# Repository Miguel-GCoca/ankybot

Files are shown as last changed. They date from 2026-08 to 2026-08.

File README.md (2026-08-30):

# Ankybot

A custom 12-DOF quadruped robot, trained in NVIDIA Isaac Lab (PPO) and deployed via ROS 2 to a Raspberry Pi 5 + Arduino Uno R3 servo system.

Training montage and demo clips are in [`media/`](media/) — see
`media/training_montage/ankybot_v2_training_montage/rl-video-step-6000.mp4` for
the latest checkpoint's gait, or `media/ankybot_v1.mp4` for a hardware demo.

See [`ENGINEERING.md`](ENGINEERING.md) for a write-up of the harder problems
that came up along the way — a reward-gaming exploit found via playback, a
sim-to-real actuator recalibration, and an ablation study that root-caused a
standing-instability bug to noisy real joint-velocity feedback.

See [`RESTORE.md`](RESTORE.md) for the exact Isaac Sim/Isaac Lab versions this
was built against and how to stand the environment back up from scratch.

## Repo layout

```
training/
  ankybot_v2/     Isaac Lab RL training project — 12-DOF locomotion policy (PPO, rsl_rl)
  ankybot_v3/     Next-generation training project — expanded gait/behavior experiments
                  (standing, walking, multiple gait variants); raw per-iteration
                  checkpoints and TensorBoard logs are gitignored, only final
                  exported policies + run metadata are kept
  custom_assets/  Robot USD descriptions (v1/v2/v3) referenced by the training
                  configs via hard-coded path — see note below

deployment/
  catbot_ws/      ROS 2 workspace: IMU driver, I2C servo bridge, and policy runner
                  nodes that run onboard the Raspberry Pi 5
  hardware/       Robot description (URDF/USD, SolidWorks exports), servo
                  characterization data, and standalone policy deployment scripts

media/            Training montage videos and hardware demo clips
```

## Pipeline

1. **Train** a locomotion policy in Isaac Lab (`training/`), using a 48-observation
   layout (IMU angular velocity, projected gravity, IMU linear acceleration,
   velocity command, joint positions/velocities, previous action) and 12
   joint-position actions.
2. **Validate** the exported policy (`exported/policy.pt` / `policy.onnx`) in sim
   across forward, lateral, and yaw motions.
3. **Deploy** onboard via the ROS 2 `ankybot_policy_runner` node
   (`deployment/catbot_ws/src/ankybot_policy_runner`), which loads the ONNX
   policy and drives the physical servos through the I2C bridge.

## Note on running the training projects

`ankybot_v2.py` and `ankybot_v3.py` hard-code an absolute path to their USD
asset (`/workspace/custom_assets/...`), matching the layout inside the
original `isaac-lab-base` Docker container. To run either project outside
that container, either recreate the same absolute path or update the path in
the task config to point at this repo's `training/custom_assets/`.

## Status

Complete! Awarded "Faculty's Choice" at University of Central Florida Summer '26 senior design showcase.

## License

MIT — see [`LICENSE`](LICENSE).

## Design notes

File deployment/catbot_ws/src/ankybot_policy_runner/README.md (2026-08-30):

# ankybot_policy_runner — fixing "too fast / steps too small"

Observed on hardware with `low_gait_v1_rec1`: gait cadence looks too fast and
individual steps are too short compared to what the sim trained. Root cause
diagnosed 2026-07-19: `action_filter_alpha` in `config/ankybot_policy.yaml`
heavily low-pass-filters the policy's raw output before it's scaled into a
joint target, and this filter has **no counterpart in the sim the policy was
trained in** — sim applies the raw scaled action directly, every step, with
no smoothing. See MANUAL.txt for how the filter math works.

Changes below, roughly ordered by how directly they target the diagnosed
cause. None of these have been tried on hardware yet — test one at a time so
you can tell what actually moved the needle.

## 1. Lower `action_filter_alpha` (most direct fix)

`config/ankybot_policy.yaml`, `action_filter_alpha: 0.8` -> try something
lower. At `alpha=0.8` the filtered action only moves 20% of the way to the
new raw output per 20ms tick (effective lag ~100ms, about 5 control periods)
- more than enough to clip the peak amplitude off a fast leg swing before it
completes. Suggested path: step it down incrementally (e.g. 0.8 -> 0.5 ->
0.3 -> 0.0) rather than jumping straight to 0, since there may be an
undocumented reason it was set this high (taming real servo/feedback jitter,
protecting mechanics from abrupt commands) that a sudden drop to 0 could
re-expose. Watch for: stride length recovering (good), buzzing/oscillating
joints or servo chatter appearing (bad, back off).

This is a runtime YAML value — no rebuild needed, just edit and relaunch.

## 2. Train the filter into the policy instead of removing it

If dropping `action_filter_alpha` reintroduces jitter/instability that it
was actually needed for, the better long-term fix is to add an equivalent
smoothing step inside the sim actuator/action pipeline during training, so
the policy learns a gait that already accounts for filtered output, instead
of learning an unfiltered gait and then filtering it after the fact at
deploy time. This is a training-side change (not in this package) — flag it
back to the Isaac Lab side if option 1 alone doesn't resolve it.

## 3. Re-check `action_scale` / `action_clip` after any retrain

Currently `action_scale: 0.4` and `action_clip: 1.4923` match
`ActionsCfg.joint_position` in `ankybot_v3.py` exactly, so they are not the
cause of the current symptom. But these are two independent files that have
to be kept in sync by hand — if `ankybot_v3.py`'s `scale`/`clip` ever change
in a future retrain, this yaml needs the same update or you get exactly this
class of bug again (silent amplitude mismatch, no error, no crash).

## 4. Verify real control-loop timing matches `control_dt`

`control_dt: 0.02` (50Hz) must match what the policy was actually trained
at (`decimation(10) * sim.dt(0.002)`). The joint-feedback path has
documented jitter (~2-36ms spread depending on sensor, see the main
project CLAUDE.md's "Hardware Feedback Layer"/IMU sections) — if the real
achieved loop rate drifts meaningfully from 50Hz, that's a second source of
timing mismatch between what the policy expects and what it gets, on top of
the filter. Not the primary suspect here, but worth ruling out if lowering
`action_filter_alpha` alone doesn't fully fix stride length.

## 5. Consider deploying a newer checkpoint

`low_gait_v1_rec1` was trained under the original provisional PD gains
(stiffness 20/20/18, damping 0.8), before the datasheet-derived stiffness/
damping and the measured command-delay actuator (`DelayedPDActuatorCfg`,
0-30ms) were added. The current best checkpoint in the same resume-chain
lineage is `low_gait/v2_recovery2_rand` (already exported to
`catbot_ws/policies/v2_recovery2_rand_2997/`). Because that policy was
trained with a modeled command delay already baked in, it may need *less*
deploy-side smoothing to behave well than `v1_rec1` did — worth testing
after trying option 1, not instead of it, since it's a different variable.

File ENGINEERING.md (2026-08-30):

# Engineering Notes

This project kept a very detailed internal dev log throughout — day-by-day
training runs, root-cause diagnoses, every fix and why it was made. This file
is a curated, human-readable summary of the parts of that log worth reading:
the real engineering problems that came up training and deploying a from-scratch
quadruped, and how they were tracked down.

## Training a policy that doesn't cheat

The reward function for this robot combines velocity tracking, a three-leg
gait-stance term, foot air-time shaping, foot-clearance shaping, and a set of
posture/safety penalties (joint limits, base orientation, base height).
Partway through one training run, playback showed the policy rocking back and
forth in place with periodic single-leg lifts — not walking at all, but still
climbing in reward.

Root cause: the gait-stance and foot-air-time terms rewarded "correct foot
contact pattern" with no reference to whether the robot was actually
translating. A stationary rocking motion satisfies "three feet grounded,
fourth foot lifts and lands" just as well as a real stride, so the policy
found the cheaper solution. The fix was to gate both reward terms on real
measured planar body velocity *projected onto the commanded direction* (not
just speed magnitude — an early version of the fix still let a fast enough
rock clear the bar on both halves of its cycle, since raw speed doesn't know
which way it's pointing). Combined with a new asymmetric penalty on backward
drift, this closed the exploit without hand-tuning weights back down.

## Sim-to-real: replacing datasheet numbers with measured ones

The actuator model started from datasheet PD gains. Once hardware was
available, several of the sim's physical assumptions turned out to be wrong
enough to matter:

- **Actuation delay** — measured directly (command-to-motion latency across
  multiple joints/types), giving a much narrower and later-starting delay
  window than the original curve-fit estimate, which had been contaminated by
  the servo's own slow-rise dynamics rather than pure delay.
- **Stiffness/damping** — re-derived from real step-response data (small-angle
  sweeps) combined with actual per-joint moment of inertia pulled from the
  CAD mass-properties reports, instead of datasheet torque/speed constants.
  The real numbers were substantially softer and, once combined with real
  inertia, revealed the datasheet-derived config had actually been
  *overdamped* relative to hardware — the fitted config is underdamped,
  matching the overshoot actually seen on the real servos.

Each of these was treated explicitly as a distributional shift for the RL
policy (not just a config tweak) — checkpoints trained under the old values
were not assumed to transfer, and were re-validated or retrained rather than
silently continued.

## Root-causing "the robot can't hold a stand-still command"

The most involved debugging thread: commanded to stand still, the robot
instead produced large continuous joint motion. Investigation ruled out
several plausible causes before landing on the real one:

1. **IMU data** — a bag showed `/imu/data` publishing at ~0.24 Hz instead of
   its configured 50 Hz. This looked like the obvious suspect, but directly
   replaying the trained actor network with the IMU input frozen vs. live
   showed only a ~0.3% effect on the output actions — the policy's trained
   `lin_accel` distribution already has enormous natural variance (footfall
   impact transients), so a stale reading isn't a meaningful outlier against
   it. Real, but not the cause.
2. **Joint velocity feedback** — replaying the same network with real
   hardware velocity *spikes* (15–21 rad/s, captured from live feedback)
   substituted in produced a ~36% swing in raw output actions — two orders of
   magnitude larger than the IMU test. The policy's trained joint-velocity
   distribution has a standard deviation of roughly 0.7–2.6 rad/s, so real
   spikes were landing 6–20+ standard deviations outside anything the policy
   had ever seen in simulation.

This is the same class of bug in both cases — a noisy real sensor feeding a
policy that was never trained on that noise — but only direct ablation against
the actual trained network (not just staring at the bag) separated the real
cause from the plausible-looking one. The eventual fix removed joint velocity
from the observation contract entirely rather than continuing to chase
filtering/smoothing on a signal the hardware couldn't deliver cleanly.

## I2C bus contention: why the IMU kept dying

Separately from the above, the IMU would run at a clean, correct rate when
launched alone, then collapse to near-zero messages once the rest of the
stack was running. Bringing every node up one at a time while logging to
`/rosout` and watching `/imu/data`'s rate over each 5-second window pinned
the exact trigger: the IMU ran perfectly for the ~10 seconds it was alone,
then collapsed the moment the microcontroller-feedback poller started issuing
its own I2C transactions at 200 Hz — both processes were opening the same
physical I2C bus with no shared arbitration. Fix: split the two devices onto
separate Pi I2C bus controllers (a hardware/wiring change, not just
software), which resolved the contention completely and was verified with
`i2cdetect` showing clean per-bus device isolation afterward.

## An iterative recovery curriculum

Rather than training a single flat locomotion policy, later stages of this
project trained a curriculum: a base walking policy, then successive
"recovery" stages that start from progressively wider randomized joint/pose
resets (so the policy learns to recover from being knocked over or
mis-started, not just to walk from a clean stand), then domain randomization
(mass, center-of-mass, friction), then external pushes. Each stage resumes
training from the previous stage's checkpoint rather than restarting from
scratch — except at the handful of points where the observation space, action
scale, or default pose itself changed, which are hard breaks a resumed
checkpoint can't load across, and were treated as explicit from-scratch
restarts.

## Result

Ankybot was awarded **"Faculty's Choice"** at the University of Central
Florida Summer '26 senior design showcase.

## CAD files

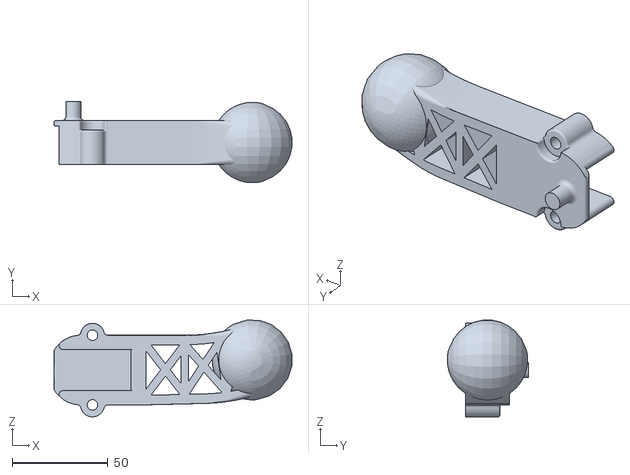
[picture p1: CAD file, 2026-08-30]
deployment/hardware/URDFs/save/FLFoot.STL
124.3 x 42.5 x 50.5

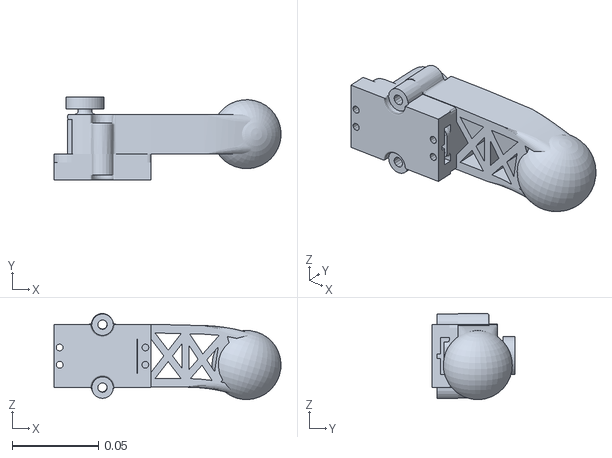
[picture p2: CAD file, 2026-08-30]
training/custom_assets/Ankybot_v3_description/FinalRemakeURDF.SLDASM/meshes/FR_Foot_Link.STL
0.131 x 0.048 x 0.0498

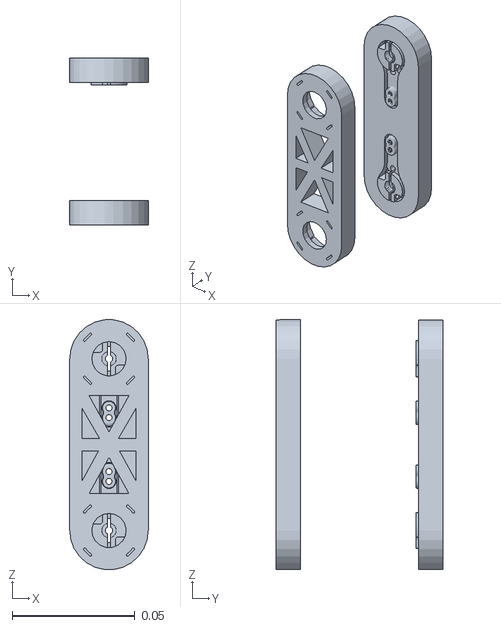
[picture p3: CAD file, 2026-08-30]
training/custom_assets/Ankybot_v3_description/FinalRemakeURDF.SLDASM/meshes/BL_Thigh_Link.STL
0.032 x 0.0679 x 0.102

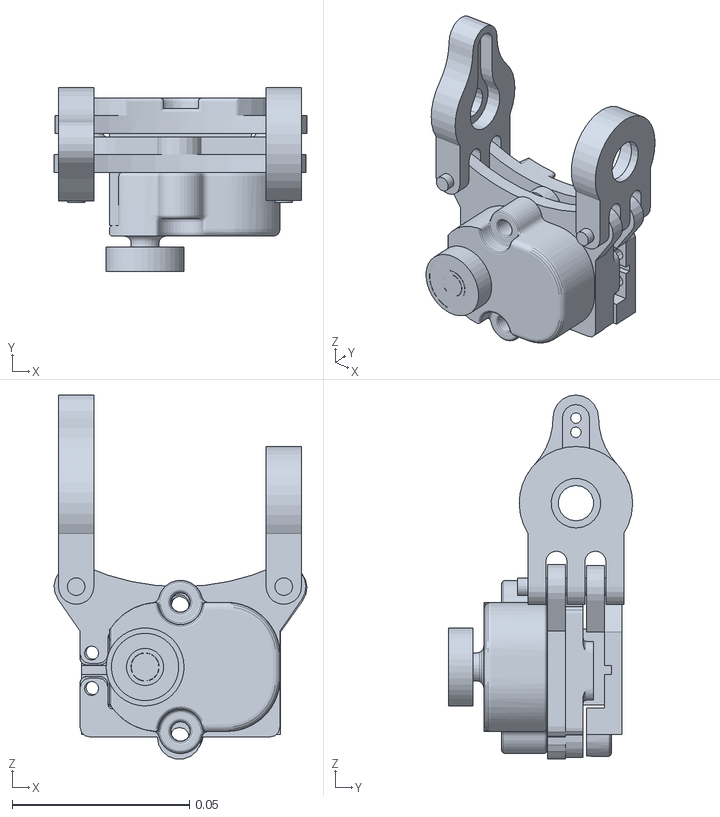
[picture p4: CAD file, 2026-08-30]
training/custom_assets/Ankybot_v3_description/FinalRemakeURDF.SLDASM/meshes/FL_Hip_Link.STL
0.0714 x 0.052 x 0.103

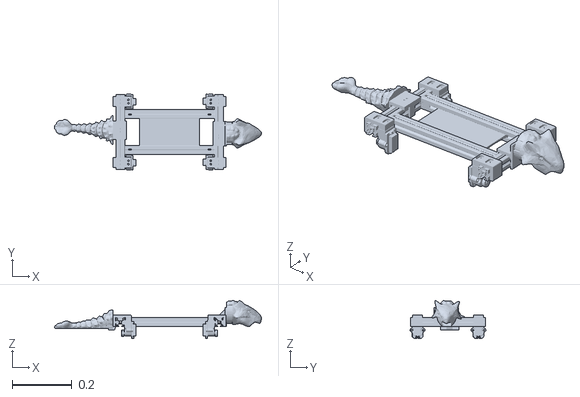
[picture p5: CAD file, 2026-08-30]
training/custom_assets/Ankybot_v3_description/FinalRemakeURDF.SLDASM/meshes/Base_Link.STL
0.692 x 0.254 x 0.127

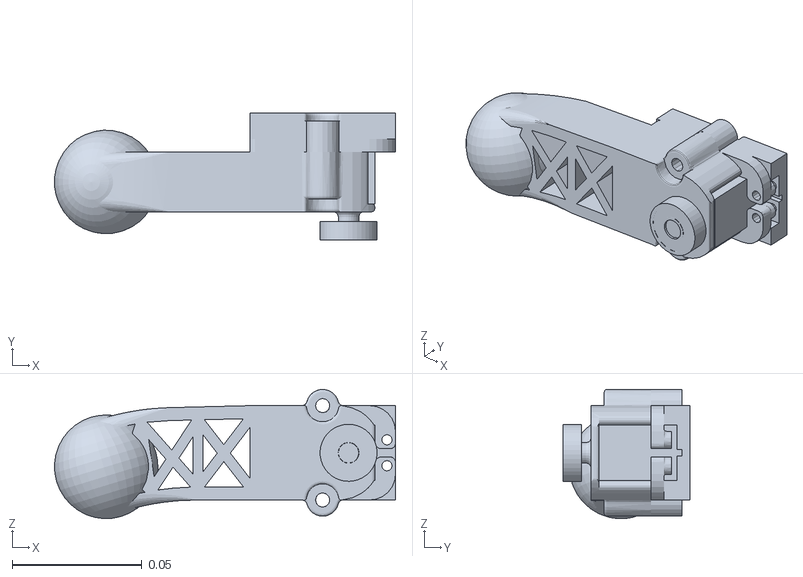
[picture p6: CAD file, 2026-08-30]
training/custom_assets/Ankybot_v3_description/FinalRemakeURDF.SLDASM/meshes/BL_Foot_Link.STL
0.132 x 0.0488 x 0.0498

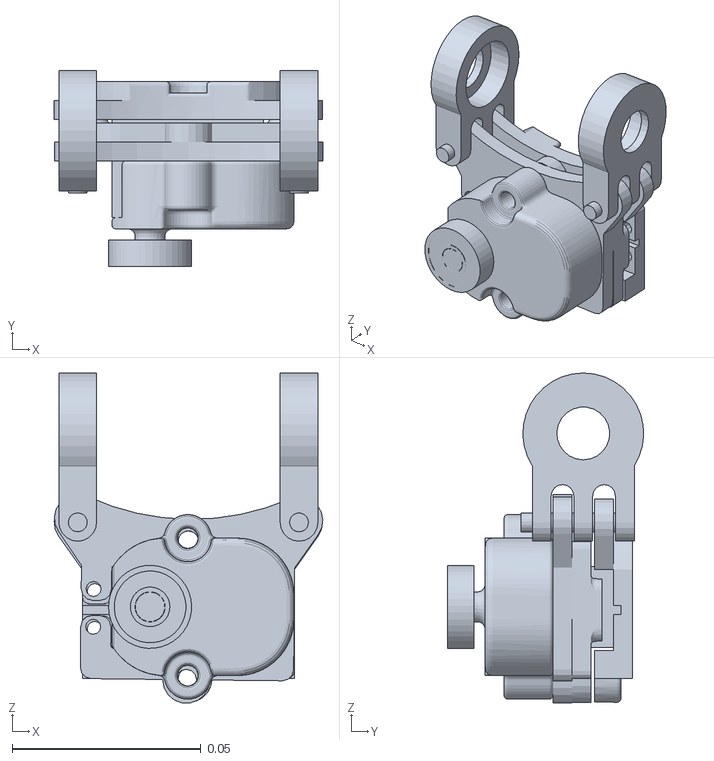
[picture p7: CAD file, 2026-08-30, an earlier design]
deployment/hardware/URDFs/ankybot_v2/FinalURDF.SLDASM/meshes/FLHip.STL
0.0712 x 0.052 x 0.0874

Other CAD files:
deployment/hardware/URDFs/save/FRFoot.STL
training/custom_assets/Ankybot_v3_description/FinalRemakeURDF.SLDASM/meshes/FL_Thigh_Link.STL
deployment/hardware/URDFs/save/BLFoot.STL
training/custom_assets/Ankybot_v3_description/FinalRemakeURDF.SLDASM/meshes/FR_Thigh_Link.STL
training/custom_assets/Ankybot_v3_description/FinalRemakeURDF.SLDASM/meshes/FR_Hip_Link.STL
training/custom_assets/Ankybot_v3_description/FinalRemakeURDF.SLDASM/meshes/BR_Foot_Link.STL
training/custom_assets/Ankybot_v3_description/FinalRemakeURDF.SLDASM/meshes/FL_Foot_Link.STL
training/custom_assets/Ankybot_v3_description/FinalRemakeURDF.SLDASM/meshes/BR_Hip_Link.STL
training/custom_assets/Ankybot_v3_description/FinalRemakeURDF.SLDASM/meshes/BR_Thigh_Link.STL
training/custom_assets/Ankybot_v3_description/FinalRemakeURDF.SLDASM/meshes/BL_Hip_Link.STL
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

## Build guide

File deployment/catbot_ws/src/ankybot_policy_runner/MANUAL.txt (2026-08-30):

ankybot_policy_runner parameter manual
==========================================

This covers the parameters in config/ankybot_policy.yaml (and the matching
declare_parameter calls in policy_runner.py). Each control tick (every
control_dt seconds) the node builds a 48-value observation, runs it through
the ONNX policy, and turns the output into a joint target published on
/joint_commands. The paragraphs below walk that pipeline in order.

action_scale and action_clip together define how the policy's raw output
turns into radians: the raw output is first clipped to +/-action_clip, then
multiplied by action_scale, then added to each joint's default position.
These two MUST match ActionsCfg.joint_position in the sim training config
exactly (scale=0.4, clip=(-1.4923, 1.4923) currently), they are not tuning
knobs, they are a contract with whatever policy.onnx you load. Changing
either one without retraining just makes every commanded joint angle wrong
by a fixed multiplicative/clipping factor: raising action_scale makes every
motion larger and more likely to slam into joint limits or the effort
limit; lowering it makes every motion smaller and gait tracking will
generally get worse since the policy's chosen actions no longer reach where
it intended them to.

action_filter_alpha controls exponential smoothing applied to the raw
policy output before it's scaled into a joint target:
filtered = alpha*filtered + (1-alpha)*raw. At alpha=0 there is no smoothing
at all (matches how the sim actually trained the policy, raw action
applied directly every step). As alpha approaches 1, the filtered value
barely moves each tick, meaning fast/large commanded swings get cut down in
amplitude before they're ever reached, and the effective response lags the
policy's true intent by roughly control_dt/(1-alpha) seconds. This is a
pure deploy-time addition with no equivalent in training, so it is the
single most likely place for a "trained motion doesn't match observed
motion" mismatch to hide. Higher alpha = smoother/safer-looking but
smaller and more delayed motion; lower alpha = truer to what the policy
actually learned, but any real jitter/noise that alpha was compensating for
(deliberately or not) will show up more directly in servo commands.

control_dt sets both the timer period the node runs its control loop at
and (implicitly, via the observation the policy expects) the rate the
policy was trained to be queried at. It must equal decimation*sim.dt from
the training env config (currently 10*0.002=0.02s, 50Hz). Changing this
without retraining desyncs the policy's internal notion of "how much time
passes between actions" from reality, a real robot running slower or
faster than the trained rate will drift from the intended dynamics even
though the maths look identical every step.

default_joint_pos_rad and joint_names define the zero-point and ordering
the policy was trained around: every joint target is default_pos +
scale*filtered_action, so if this array doesn't match the *specific
deployed checkpoint's own* training pose exactly, every joint's actual
angle is offset from what the policy assumes its own action means, and
joint_names' order must match the training joint order (type-first,
alphabetical by leg) or entire limbs get scrambled onto the wrong physical
servo. Currently hip=0, thigh=+0.5236 rad, foot=+0.5236 rad, matching
logs/rsl_rl/v4/base_scratch_feet30/params/env.yaml. Always check the
deployed checkpoint's own params/env.yaml while pose experiments are
ongoing, not ankybot_v3.py's live value.

max_joint_vel_rad_s and publish_rate_hz apply after action_filter_alpha:
max_joint_vel_rad_s hard-caps how far the goal can move per control tick
(rad/s), and publish_rate_hz subdivides each tick's move into smaller
interpolated sub-steps so a real servo (no compliance, unlike sim's
actuator model) doesn't see discrete snaps. See ankybot_policy.yaml's own
comments for further detail on both.

cmd_vel_timeout is a safety cutoff, unrelated to gait shape: if no
/cmd_vel message has arrived within this many seconds, the commanded
velocity is zeroed out before being fed to the policy (so a lost
connection results in the robot trying to stand still, not continuing to
run the last command blind). Raising it makes the robot keep obeying a
stale command for longer after a comms drop; lowering it makes it revert
to standing-still sooner, at the cost of being more sensitive to brief
/cmd_vel gaps under normal operation.

The four topic parameters (imu_topic, cmd_vel_topic, joint_states_topic,
servo_cmd_topic) just point the node at the right ROS topics, changing
these doesn't affect gait behavior at all, only which topics the data
flows through, and only matters if the rest of the pipeline (IMU
publisher, joystick/teleop node, serial/I2C bridge) is remapped to match.

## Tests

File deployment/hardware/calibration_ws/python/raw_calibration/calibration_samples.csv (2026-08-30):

t_s | target_deg | phase | raw | mean | margin
0.000 | +90.0 | settle | 122.00
0.053 | +90.0 | settle | 121.00
0.106 | +90.0 | settle | 124.00
0.159 | +90.0 | settle | 122.00
0.212 | +90.0 | settle | 124.00
0.264 | +90.0 | settle | 122.00
0.317 | +90.0 | settle | 123.00
0.370 | +90.0 | settle | 128.00
0.423 | +90.0 | settle | 122.00
0.476 | +90.0 | settle | 122.00
0.528 | +90.0 | settle | 122.00
0.581 | +90.0 | settle | 122.00
0.634 | +90.0 | settle | 121.00
0.687 | +90.0 | settle | 122.00
0.740 | +90.0 | settle | 123.00
0.792 | +90.0 | settle | 123.00
0.845 | +90.0 | settle | 122.00
0.898 | +90.0 | settle | 122.00
0.951 | +90.0 | settle | 123.00
1.004 | +90.0 | settle | 121.00
1.056 | +90.0 | settle | 122.00
1.109 | +90.0 | settle | 121.00
1.162 | +90.0 | settle | 122.00
1.215 | +90.0 | settle | 122.00
1.268 | +90.0 | settle | 122.00
1.320 | +90.0 | settle | 123.00
1.373 | +90.0 | settle | 121.00
1.426 | +90.0 | settle | 123.00
1.479 | +90.0 | settle | 123.00
1.532 | +90.0 | settle | 122.00
1.584 | +90.0 | settle | 122.00
1.637 | +90.0 | settle | 122.00
1.690 | +90.0 | settle | 122.00
1.743 | +90.0 | settle | 123.00
1.796 | +90.0 | settle | 122.00
0.003 | +90.0 | measure | 122.00
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

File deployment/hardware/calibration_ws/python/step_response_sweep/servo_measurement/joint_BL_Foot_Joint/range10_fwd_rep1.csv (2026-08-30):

t_us | cmd_deg | meas_deg
2759 | 5.0 | -5.044248387074636
5487 | 5.0 | -5.044248387074636
8211 | 5.0 | -5.044248387074636
10934 | 5.0 | -5.044248387074636
13659 | 5.0 | -30.000000869106053
16387 | 5.0 | -30.000000869106053
19114 | 5.0 | -30.000000869106053
21844 | 5.0 | -30.000000869106053
24568 | 5.0 | -30.000000869106053
27289 | 5.0 | -30.000000869106053
30010 | 5.0 | -22.566371307617686
32731 | 5.0 | -22.566371307617686
35452 | 5.0 | -22.566371307617686
38172 | 5.0 | -13.539823809098989
40892 | 5.0 | -13.539823809098989
43613 | 5.0 | -13.539823809098989
46335 | 5.0 | -13.539823809098989
49056 | 5.0 | -2.920353250908077
51782 | 5.0 | -2.920353250908077
54502 | 5.0 | -2.920353250908077
57224 | 5.0 | 3.451328742497011
59945 | 5.0 | 3.451328742497011
62666 | 5.0 | 3.451328742497011
65386 | 5.0 | 3.451328742497011
68109 | 5.0 | 3.451328742497011
70837 | 5.0 | 3.451328742497011
73558 | 5.0 | 3.9823008189913565
76279 | 5.0 | 3.9823008189913565
79002 | 5.0 | 3.9823008189913565
81722 | 5.0 | 3.9823008189913565
84443 | 5.0 | 5.044248387074636
87163 | 5.0 | 5.044248387074636
89884 | 5.0 | 5.044248387074636
92606 | 5.0 | 5.575220463568981
95326 | 5.0 | 5.575220463568981
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

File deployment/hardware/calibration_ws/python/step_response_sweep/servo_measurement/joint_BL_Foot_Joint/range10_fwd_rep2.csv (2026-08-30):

t_us | cmd_deg | meas_deg
2763 | 5.0 | -2.920353250908077
5490 | 5.0 | -2.920353250908077
8213 | 5.0 | -1.3274336063304522
10937 | 5.0 | -1.3274336063304522
13658 | 5.0 | -1.3274336063304522
16386 | 5.0 | -30.000000869106053
19113 | 5.0 | -30.000000869106053
21837 | 5.0 | -30.000000869106053
24569 | 5.0 | -21.5044254470817
27293 | 5.0 | -21.5044254470817
30013 | 5.0 | -21.5044254470817
32736 | 5.0 | -21.5044254470817
35459 | 5.0 | -16.194691021759894
38180 | 5.0 | -16.194691021759894
40901 | 5.0 | -16.194691021759894
43624 | 5.0 | -1.3274336063304522
46348 | 5.0 | -1.3274336063304522
49069 | 5.0 | -1.3274336063304522
51789 | 5.0 | 2.920353250908077
54511 | 5.0 | 2.920353250908077
57238 | 5.0 | 2.920353250908077
59958 | 5.0 | 4.513272895485701
62678 | 5.0 | 4.513272895485701
65401 | 5.0 | 4.513272895485701
68127 | 5.0 | 4.513272895485701
70855 | 5.0 | 5.044248387074636
73576 | 5.0 | 5.044248387074636
76298 | 5.0 | 5.044248387074636
79019 | 5.0 | 5.044248387074636
81744 | 5.0 | 5.044248387074636
84465 | 5.0 | 5.044248387074636
87187 | 5.0 | 5.044248387074636
89907 | 5.0 | 5.044248387074636
92634 | 5.0 | 5.044248387074636
95354 | 5.0 | 5.575220463568981
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

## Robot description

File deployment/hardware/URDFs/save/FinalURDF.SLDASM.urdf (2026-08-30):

<?xml version="1.0" encoding="utf-8"?>
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
<robot name="FinalURDF.SLDASM">
  <link name="Base_Link">
    <inertial>
      <origin xyz="7.3348E-05 -0.00013963 -0.0079498" rpy="0 0 0" />
      <mass value="1.0503" />
      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
    </inertial>
    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
  </link>
  <link name="FR_Hip_Link">
    <inertial>
      <origin xyz="0.00092086 0.0053269 -0.038601" rpy="0 0 0" />
      <mass value="0.11316" />
      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
    </inertial>
    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
  </link>
  <joint name="FR_Hip_Joint" type="revolute">
    <origin xyz="0.1045 -0.099089 -0.035652" rpy="0 0 0" />
    <parent link="Base_Link" />
    <child link="FR_Hip_Link" />
    <axis xyz="-1 0 0" />
    <limit lower="-1.57079632679" upper="1.57079632679" effort="3.92266" velocity="10.4719755" />
  </joint>
  <link name="FR_Thigh_Link">
    <inertial>
      <origin xyz="-0.014685 -3.4417E-15 -0.02616" rpy="0 0 0" />
      <mass value="0.043631" />
      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
    </inertial>
    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
  </link>
  <joint name="FR_Thigh_Joint" type="revolute">
    <origin xyz="-0.010143 0.0050417 -0.045931" rpy="0 0 0" />
    <parent link="FR_Hip_Link" />
    <child link="FR_Thigh_Link" />
    <axis xyz="0 1 0" />
    <limit lower="-1.57079632679" upper="1.57079632679" effort="3.92266" velocity="10.4719755" />
  </joint>
  <link name="FR_Foot_Link">
    <inertial>
      <origin xyz="0.024442 0.0054487 -0.034356" rpy="0 0 0" />
      <mass value="0.1583" />
      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
    </inertial>
    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
  </link>
  <joint name="FR_Foot_Joint" type="revolute">
    <origin xyz="-0.02937 0 -0.05232" rpy="0 0 0" />
    <parent link="FR_Thigh_Link" />
    <child link="FR_Foot_Link" />
    <axis xyz="0 1 0" />
    <limit lower="-1.57079632679" upper="1.57079632679" effort="3.92266" velocity="10.4719755" />
  </joint>
  <link name="FL_Hip_Link">
    <inertial>
      <origin xyz="0.00092086 -0.0053268 -0.038601" rpy="0 0 0" />
      <mass value="0.11316" />
      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
    </inertial>
    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
  </link>
  <joint name="FL_Hip_Joint" type="revolute">
    <origin xyz="0.1045 0.098749 -0.035742" rpy="0 0 0" />
    <parent link="Base_Link" />
    <child link="FL_Hip_Link" />
    <axis xyz="-1 0 0" />
    <limit lower="-1.57079632679" upper="1.57079632679" effort="3.92266" velocity="10.4719755" />
  </joint>
  <link name="FL_Thigh_Link">
    <inertial>
      <origin xyz="-0.014685 3.1225E-17 -0.02616" rpy="0 0 0" />
      <mass value="0.043631" />
      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
    </inertial>
    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
  </link>
  <joint name="FL_Thigh_Joint" type="revolute">
    <origin xyz="-0.010143 -0.0050417 -0.045931" rpy="0 0 0" />
    <parent link="FL_Hip_Link" />
    <child link="FL_Thigh_Link" />
    <axis xyz="0 1 0" />
    <limit lower="-1.57079632679" upper="1.57079632679" effort="3.92266" velocity="10.4719755" />
  </joint>
  <link name="FL_Foot_Link">
    <inertial>
      <origin xyz="0.024442 -0.0063159 -0.034446" rpy="0 0 0" />
      <mass value="0.1583" />
      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
    </inertial>
    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
  </link>
  <joint name="FL_Foot_Joint" type="revolute">
    <origin xyz="-0.02937 0 -0.05223" rpy="0 0 0" />
    <parent link="FL_Thigh_Link" />
    <child link="FL_Foot_Link" />
    <axis xyz="0 1 0" />
    <limit lower="-1.57079632679" upper="1.57079632679" effort="3.92266" velocity="10.4719755" />
  </joint>
  <link name="BR_Hip_Link">
    <inertial>
      <origin xyz="-0.00092224 0.0053268 -0.038601" rpy="0 0 0" />
      <mass value="0.11316" />
      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
    </inertial>
    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
  </link>
  <joint name="BR_Hip_Joint" type="revolute">
    <origin xyz="-0.1045 -0.099089 -0.035652" rpy="0 0 0" />
    <parent link="Base_Link" />
    <child link="BR_Hip_Link" />
    <axis xyz="1 0 0" />
    <limit lower="-1.57079632679" upper="1.57079632679" effort="3.92266" velocity="10.4719755" />
  </joint>
  <link name="BR_Thigh_Link">
    <inertial>
      <origin xyz="0.014685 -3.7748E-15 -0.02616" rpy="0 0 0" />
      <mass value="0.043631" />
      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
    </inertial>
    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
  </link>
  <joint name="BR_Thigh_Joint" type="revolute">
    <origin xyz="0.010142 0.0050417 -0.045931" rpy="0 0 0" />
    <parent link="BR_Hip_Link" />
    <child link="BR_Thigh_Link" />
    <axis xyz="0 1 0" />
    <limit lower="-1.57079632679" upper="1.57079632679" effort="3.92266" velocity="10.4719755" />
  </joint>
  <link name="BR_Foot_Link">
    <inertial>
      <origin xyz="-0.024617 0.0063159 -0.034142" rpy="0 0 0" />
      <mass value="0.1583" />
      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
    </inertial>
    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
  </link>
  <joint name="BR_Foot_Joint" type="revolute">
    <origin xyz="0.029371 0 -0.05241" rpy="0 0 0" />
    <parent link="BR_Thigh_Link" />
    <child link="BR_Foot_Link" />
    <axis xyz="0 1 0" />
    <limit lower="-1.57079632679" upper="1.57079632679" effort="3.92266" velocity="10.4719755" />
  </joint>
  <link name="BL_Hip_Link">
    <inertial>
      <origin xyz="-0.00092086 -0.0053269 -0.038601" rpy="0 0 0" />
      <mass value="0.11316" />
      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
    </inertial>
    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
  </link>
  <joint name="BL_Hip_Joint" type="revolute">
    <origin xyz="-0.1045 0.098749 -0.035742" rpy="0 0 0" />
    <parent link="Base_Link" />
    <child link="BL_Hip_Link" />
    <axis xyz="1 0 0" />
    <limit lower="-1.57079632679" upper="1.57079632679" effort="3.92266" velocity="10.4719755" />
  </joint>
  <link name="BL_Thigh_Link">
    <inertial>
      <origin xyz="0.014685 9.0206E-17 -0.02616" rpy="0 0 0" />
      <mass value="0.043631" />
      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
    </inertial>
    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
  </link>
  <joint name="BL_Thigh_Joint" type="revolute">
    <origin xyz="0.010143 -0.0042 -0.045931" rpy="0 0 0" />
    <parent link="BL_Hip_Link" />
    <child link="BL_Thigh_Link" />
    <axis xyz="0 1 0" />
    <limit lower="-1.57079632679" upper="1.57079632679" effort="3.92266" velocity="10.4719755" />
  </joint>
  <link name="BL_Foot_Link">
    <inertial>
      <origin xyz="-0.024629 -0.0055046 -0.034197" rpy="0 0 0" />
      <mass value="0.1583" />
      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
    </inertial>
    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
  </link>
  <joint name="BL_Foot_Joint" type="revolute">
    <origin xyz="0.02937 0 -0.05232" rpy="0 0 0" />
    <parent link="BL_Thigh_Link" />
    <child link="BL_Foot_Link" />
    <axis xyz="0 1 0" />
    <limit lower="-1.57079632679" upper="1.57079632679" effort="3.92266" velocity="10.4719755" />
  </joint>
</robot>

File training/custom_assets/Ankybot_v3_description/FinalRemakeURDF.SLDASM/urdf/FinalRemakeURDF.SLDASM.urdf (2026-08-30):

<?xml version="1.0" encoding="utf-8"?>
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
<robot name="FinalRemakeURDF.SLDASM">
  <link name="Base_Link">
    <inertial>
      <origin xyz="0.020672 0.0001775 -0.00016057" rpy="0 0 0" />
      <mass value="1.8396" />
      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
    </inertial>
    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
  </link>
  <link name="FR_Hip_Link">
    <inertial>
      <origin xyz="2.8582E-05 0.0050339 -0.037076" rpy="0 0 0" />
      <mass value="0.11621" />
      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
    </inertial>
    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
  </link>
  <joint name="FR_Hip_Joint" type="revolute">
    <origin xyz="0.12775 -0.1018 -0.040652" rpy="0 0 0" />
    <parent link="Base_Link" />
    <child link="FR_Hip_Link" />
    <axis xyz="1 0 0" />
    <limit lower="-1.57079632679" upper="1.57079632679" effort="3.92266" velocity="10.4719755" />
  </joint>
  <link name="FR_Thigh_Link">
    <inertial>
      <origin xyz="-5.0003E-08 -0.0061714 -0.035007" rpy="0 0 0" />
      <mass value="0.062712" />
      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
    </inertial>
    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
  </link>
  <joint name="FR_Thigh_Joint" type="revolute">
    <origin xyz="-0.010143 0.0050417 -0.045931" rpy="0 0 0" />
    <parent link="FR_Hip_Link" />
    <child link="FR_Thigh_Link" />
    <axis xyz="0 1 0" />
    <limit lower="-1.57079632679" upper="1.57079632679" effort="3.92266" velocity="10.4719755" />
  </joint>
  <link name="FR_Foot_Link">
    <inertial>
      <origin xyz="0.042285 0.0053727 -0.0014211" rpy="0 0 0" />
      <mass value="0.15776" />
      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
    </inertial>
    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
  </link>
  <joint name="FR_Foot_Joint" type="revolute">
    <origin xyz="0 0 -0.07" rpy="0 0 0" />
    <parent link="FR_Thigh_Link" />
    <child link="FR_Foot_Link" />
    <axis xyz="0 1 0" />
    <limit lower="-1.57079632679" upper="1.57079632679" effort="3.92266" velocity="10.4719755" />
  </joint>
  <link name="FL_Hip_Link">
    <inertial>
      <origin xyz="0.00022325 -0.0050353 -0.037386" rpy="0 0 0" />
      <mass value="0.11621" />
      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
    </inertial>
    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
  </link>
  <joint name="FL_Hip_Joint" type="revolute">
    <origin xyz="0.12775 0.1018 -0.040652" rpy="0 0 0" />
    <parent link="Base_Link" />
    <child link="FL_Hip_Link" />
    <axis xyz="1 0 0" />
    <limit lower="-1.57079632679" upper="1.57079632679" effort="3.92266" velocity="10.4719755" />
  </joint>
  <link name="FL_Thigh_Link">
    <inertial>
      <origin xyz="5.0034E-08 0.0061714 -0.035007" rpy="0 0 0" />
      <mass value="0.062712" />
      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
    </inertial>
    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
  </link>
  <joint name="FL_Thigh_Joint" type="revolute">
    <origin xyz="-0.00985 -0.0050417 -0.046234" rpy="0 0 0" />
    <parent link="FL_Hip_Link" />
    <child link="FL_Thigh_Link" />
    <axis xyz="0 1 0" />
    <limit lower="-1.57079632679" upper="1.57079632679" effort="3.92266" velocity="10.4719755" />
  </joint>
  <link name="FL_Foot_Link">
    <inertial>
      <origin xyz="0.042285 -0.0062428 -0.0014211" rpy="0 0 0" />
      <mass value="0.15776" />
      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
    </inertial>
    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
  </link>
  <joint name="FL_Foot_Joint" type="revolute">
    <origin xyz="0 0 -0.07" rpy="0 0 0" />
    <parent link="FL_Thigh_Link" />
    <child link="FL_Foot_Link" />
    <axis xyz="0 1 0" />
    <limit lower="-1.57079632679" upper="1.57079632679" effort="3.92266" velocity="10.4719755" />
  </joint>
  <link name="BR_Hip_Link">
    <inertial>
      <origin xyz="0.0012423 0.0050353 -0.036602" rpy="0 0 0" />
      <mass value="0.11621" />
      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
    </inertial>
    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
  </link>
  <joint name="BR_Hip_Joint" type="revolute">
    <origin xyz="-0.12875 -0.1018 -0.040742" rpy="0 0 0" />
    <parent link="Base_Link" />
    <child link="BR_Hip_Link" />
    <axis xyz="1 0 0" />
    <limit lower="-1.57079632679" upper="1.57079632679" effort="3.92266" velocity="10.4719755" />
  </joint>
  <link name="BR_Thigh_Link">
    <inertial>
      <origin xyz="2.9465E-06 -0.0061714 -0.035007" rpy="0 0 0" />
      <mass value="0.062712" />
      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
    </inertial>
    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
  </link>
  <joint name="BR_Thigh_Joint" type="revolute">
    <origin xyz="0.011497 0.0050417 -0.045293" rpy="0 0 0" />
    <parent link="BR_Hip_Link" />
    <child link="BR_Thigh_Link" />
    <axis xyz="0 -1 0" />
    <limit lower="-1.57079632679" upper="1.57079632679" effort="3.92266" velocity="10.4719755" />
  </joint>
  <link name="BR_Foot_Link">
    <inertial>
      <origin xyz="-0.042285 0.0062428 -0.0014211" rpy="0 0 0" />
      <mass value="0.15776" />
      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
    </inertial>
    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
  </link>
  <joint name="BR_Foot_Joint" type="revolute">
    <origin xyz="0 0 -0.07" rpy="0 0 0" />
    <parent link="BR_Thigh_Link" />
    <child link="BR_Foot_Link" />
    <axis xyz="0 -1 0" />
    <limit lower="-1.57079632679" upper="1.57079632679" effort="3.92266" velocity="10.4719755" />
  </joint>
  <link name="BL_Hip_Link">
    <inertial>
      <origin xyz="-2.8582E-05 -0.0050339 -0.037166" rpy="0 0 0" />
      <mass value="0.11621" />
      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
    </inertial>
    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
  </link>
  <joint name="BL_Hip_Joint" type="revolute">
    <origin xyz="-0.12875 0.1018 -0.040652" rpy="0 0 0" />
    <parent link="Base_Link" />
    <child link="BL_Hip_Link" />
    <axis xyz="1 0 0" />
    <limit lower="-1.57079632679" upper="1.57079632679" effort="3.92266" velocity="10.4719755" />
  </joint>
  <link name="BL_Thigh_Link">
    <inertial>
      <origin xyz="5.0034E-08 0.0053296 -0.035007" rpy="0 0 0" />
      <mass value="0.062712" />
      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
    </inertial>
    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
  </link>
  <joint name="BL_Thigh_Joint" type="revolute">
    <origin xyz="0.010143 -0.0042 -0.046021" rpy="0 0 0" />
    <parent link="BL_Hip_Link" />
    <child link="BL_Thigh_Link" />
    <axis xyz="0 -1 0" />
    <limit lower="-1.57079632679" upper="1.57079632679" effort="3.92266" velocity="10.4719755" />
  </joint>
  <link name="BL_Foot_Link">
    <inertial>
      <origin xyz="-0.042266 -0.0054259 -0.0013891" rpy="0 0 0" />
      <mass value="0.15776" />
      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
    </inertial>
    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
  </link>
  <joint name="BL_Foot_Joint" type="revolute">
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

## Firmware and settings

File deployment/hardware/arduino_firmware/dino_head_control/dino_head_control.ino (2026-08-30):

#include <Servo.h>
#include <Wire.h>

// =====================================================================
//  DINO HEAD - 2 DOF (Yaw + Pitch)
//  4 modes, switched over I2C by a speech-to-text host:
//    1 = Idle             (slow random look-around) - DEFAULT ON POWER-UP
//    2 = Heard Command     (nod acknowledgment x2, then back to idle)
//    3 = Walking            (pitch bobs 0 <-> 30 continuously)
//    4 = Turning             (yaw sweeps -20 <-> +20 continuously)
//  Whatever mode is active keeps running until a different command byte
//  arrives - including going back to idle, which is its own command (1).
// =====================================================================

// ---------------------------------------------------------------
// PIN ASSIGNMENTS
// ---------------------------------------------------------------
const int YAW_PIN   = 9;   // servo mounted vertically, rotates head left/right
const int PITCH_PIN = 10;  // servo mounted on its side, tilts head up/down

// ---------------------------------------------------------------
// SERVO HARDWARE SPEC (both servos are identical 270 deg / 25kg units)
// Do not need to touch this unless you change servo hardware.
// ---------------------------------------------------------------
const int   SERVO_PULSE_MIN     = 500;   // microseconds -> mechanical -135 deg
const int   SERVO_PULSE_MAX     = 2500;  // microseconds -> mechanical +135 deg
const int   SERVO_PULSE_CENTER  = 1500;  // microseconds -> 0 deg (your zero point)
const float SERVO_HALF_RANGE_DEG = 135.0; // matches your +/-135 deg spec

// =====================================================================
//  >>> EASY-EDIT ZONE: MODE 1 - IDLE (random look-around range) <<<
// =====================================================================
float YAW_MIN_ANGLE = -60;   // how far the head can turn toward its LEFT
float YAW_MAX_ANGLE =  60;   // how far the head can turn toward its RIGHT

float PITCH_MIN_ANGLE = -5;  // how far the head can dip DOWN
float PITCH_MAX_ANGLE =  35; // how far the head can lift UP

const unsigned long MOVE_DURATION_MIN  = 1200;  // ms - fastest a look-move happens
const unsigned long MOVE_DURATION_MAX  = 2000;  // ms - slowest a look-move happens
const unsigned long PAUSE_DURATION_MIN = 800;   // ms - shortest "hold and stare"
const unsigned long PAUSE_DURATION_MAX = 2000;  // ms - longest "hold and stare"

// ---- Motion feel, applies to ALL modes ----
// Low-pass filter (0-1): lower = smoother/more lag, higher = snappier/more jitter-prone
const float POSITION_SMOOTHING = 0.5;
// Curve softness (0-1): 1.0 = full ease-in-out, 0.0 = constant speed.
// Lower this if motion looks choppy/stuttery (coarse-resolution servos).
const float EASE_SOFTNESS = 1.0;

// =====================================================================
//  >>> EASY-EDIT ZONE: I2C <<<
// =====================================================================
const byte I2C_ADDRESS = 0x5B; // slave address the dino listens on

// Command byte values the speech-to-text host sends to select a mode.
const byte CMD_IDLE          = 1;
const byte CMD_HEARD_COMMAND = 2;
const byte CMD_WALKING       = 3;
const byte CMD_TURNING       = 4;

// =====================================================================
//  >>> EASY-EDIT ZONE: MODE 2 - HEARD COMMAND (double-nod sequence) <<<
//  Waypoints run in order, each fully finishing before the next starts.
//  The actual list is assigned in setup() below (search "i2cSequence[").
// =====================================================================
const unsigned long SEQUENCE_STEP_HOLD_MS = 250; // pause held at each waypoint, ms

// =====================================================================
//  >>> EASY-EDIT ZONE: MODE 3 - WALKING (pitch bob) <<<
// =====================================================================
float WALK_DOWN_ANGLE = 0;    // pitch angle at the "down" point of the bob
float WALK_UP_ANGLE   = 30;   // pitch angle at the "up" point of the bob
const unsigned long WALK_STEP_DURATION = 800; // ms per up or down movement (bob speed)
const unsigned long WALK_HOLD_MS       = 0;   // pause at each extreme, ms (0 = continuous)

// =====================================================================
//  >>> EASY-EDIT ZONE: MODE 4 - TURNING (yaw sweep) <<<
// =====================================================================
float TURN_LEFT_ANGLE  = -20;
float TURN_RIGHT_ANGLE =  20;
const unsigned long TURN_STEP_DURATION = 1500; // ms per left or right sweep
const unsigned long TURN_HOLD_MS       = 300;  // pause at each extreme, ms

// Time given to smoothly zero the "other" axis when entering walking/turning
// (e.g. yaw centers before walking bob starts; pitch centers before turn starts)
const unsigned long MODE_SETTLE_DURATION = 500;

// ---------------------------------------------------------------
// Internal state - no need to edit below this line
// ---------------------------------------------------------------
Servo yawServo;
Servo pitchServo;

enum MotionState { MOVING, PAUSED };
enum Mode { MODE_IDLE, MODE_HEARD_COMMAND, MODE_WALKING, MODE_TURNING };
enum PhaseState { PHASE_SETTLING, PHASE_MOVING, PHASE_HOLDING };

struct Axis {
  Servo* servo;
  float minAngle;
  float maxAngle;
  float startAngle;
  float targetAngle;
  float currentAngle;    // ideal trajectory position (eased, unfiltered)
  float commandedAngle;  // actual position sent to servo (filtered/smoothed)
  unsigned long moveStart;
  unsigned long moveDuration;
  unsigned long pauseStart;
  unsigned long pauseDuration;
  MotionState state;
};

Axis yawAxis;
Axis pitchAxis;

Mode currentMode = MODE_IDLE;

volatile byte i2cCommandValue = 0;   // set inside the I2C interrupt, read in loop()
volatile bool i2cCommandPending = false;

// ---- Mode 2: heard-command sequence state ----
struct SequenceStep {
  Axis* axis;
  float targetAngle;
  unsigned long duration;
};
SequenceStep i2cSequence[6];
const int I2C_SEQUENCE_LENGTH = 6;
int sequenceIndex = 0;
PhaseState seqPhase = PHASE_MOVING;
unsigned long seqHoldStart = 0;

// ---- Modes 3 & 4: shared cyclic (walking/turning) state ----
struct CyclicModeConfig {
  Axis* primaryAxis;   // the axis that actually bobs/sweeps
  Axis* otherAxis;     // the axis that centers and holds still
  float boundA;
  float boundB;
  unsigned long stepDuration;
  unsigned long holdMs;
};
CyclicModeConfig walkConfig = { &pitchAxis, &yawAxis, WALK_DOWN_ANGLE, WALK_UP_ANGLE, WALK_STEP_DURATION, WALK_HOLD_MS };
CyclicModeConfig turnConfig = { &yawAxis, &pitchAxis, TURN_LEFT_ANGLE, TURN_RIGHT_ANGLE, TURN_STEP_DURATION, TURN_HOLD_MS };
PhaseState cyclePhase = PHASE_SETTLING;
unsigned long cycleHoldStart = 0;
bool cycleAtBoundB = false; // false = currently at/heading to boundA, true = boundB

// Smooth accel/decel curve (ease-in-out) so moves feel organic, not mechanical
float easeInOutSine(float t) {
  return -(cos(PI * t) - 1.0) / 2.0;
}

// Blends the eased curve with constant-speed motion, per EASE_SOFTNESS.
float blendedEase(float t) {
  float eased = easeInOutSine(t);
  return eased * EASE_SOFTNESS + t * (1.0 - EASE_SOFTNESS);
}

// Converts an angle (relative to center) into a servo pulse width
int angleToPulse(float angle) {
  angle = constrain(angle, -SERVO_HALF_RANGE_DEG, SERVO_HALF_RANGE_DEG);
  float pulse = SERVO_PULSE_CENTER +
                (angle / SERVO_HALF_RANGE_DEG) * (SERVO_PULSE_MAX - SERVO_PULSE_CENTER);
  return (int)pulse;
}

// Random float angle between two limits (2 decimal precision)
float randomAngle(float minA, float maxA) {
  long minL = (long)(minA * 100);
  long maxL = (long)(maxA * 100);
  return random(minL, maxL + 1) / 100.0;
}

void initAxis(Axis &axis, Servo* servo, float minAngle, float maxAngle) {
  axis.servo = servo;
  axis.minAngle = minAngle;
  axis.maxAngle = maxAngle;
  axis.currentAngle = 0;
  axis.commandedAngle = 0;
  axis.startAngle = 0;
  axis.targetAngle = randomAngle(minAngle, maxAngle);
  axis.moveStart = millis();
  axis.moveDuration = random(MOVE_DURATION_MIN, MOVE_DURATION_MAX);
  axis.state = MOVING;
}

// Points an axis toward a new target over a given duration, starting from
// wherever it currently is - this is what makes every mode transition smooth.
void startAxisMove(Axis &axis, float target, unsigned long duration) {
  axis.startAngle = axis.commandedAngle;
  axis.targetAngle = target;
  axis.moveStart = millis();
  axis.moveDuration = duration;
}

// Drives one axis toward axis.targetAngle over axis.moveDuration, through the
// filter, and reports back whether it has arrived (t >= 1.0).
bool driveAxisTrajectory(Axis &axis) {
  unsigned long now = millis();
  unsigned long elapsed = now - axis.moveStart;
  float t = (float)elapsed / (float)axis.moveDuration;
  bool arrived = false;
  if (t >= 1.0) {
    t = 1.0;
    arrived = true;
  }
  float eased = blendedEase(t);
  axis.currentAngle = axis.startAngle + (axis.targetAngle - axis.startAngle) * eased;
  axis.commandedAngle += (axis.currentAngle - axis.commandedAngle) * POSITION_SMOOTHING;
  axis.servo->writeMicroseconds(angleToPulse(axis.commandedAngle));
  return arrived;
}

// ---------------------------------------------------------------
// MODE 1: IDLE - slow, random "looking around" behavior
// ---------------------------------------------------------------
void updateStandbyAxis(Axis &axis) {
  unsigned long now = millis();

  if (axis.state == MOVING) {
    if (driveAxisTrajectory(axis)) {
      axis.state = PAUSED;
      axis.pauseStart = now;
      axis.pauseDuration = random(PAUSE_DURATION_MIN, PAUSE_DURATION_MAX);
    }
  } else { // PAUSED
    if (now - axis.pauseStart >= axis.pauseDuration) {
      axis.startAngle = axis.commandedAngle;
      axis.targetAngle = randomAngle(axis.minAngle, axis.maxAngle);
      axis.moveStart = now;
      axis.moveDuration = random(MOVE_DURATION_MIN, MOVE_DURATION_MAX);
      axis.state = MOVING;
    }
  }
}

// Restarts idle motion for an axis starting from wherever it currently is.
void resumeStandby(Axis &axis) {
  axis.startAngle = axis.commandedAngle;
  axis.currentAngle = axis.commandedAngle;
  axis.targetAngle = randomAngle(axis.minAngle, axis.maxAngle);
  axis.moveStart = millis();
  axis.moveDuration = random(MOVE_DURATION_MIN, MOVE_DURATION_MAX);
  axis.state = MOVING;
}

// ---------------------------------------------------------------
// MODE 2: HEARD COMMAND - double-nod sequence, then back to idle
// ---------------------------------------------------------------
void startSequenceStep(int idx) {
  SequenceStep &step = i2cSequence[idx];
  startAxisMove(*step.axis, step.targetAngle, step.duration);
  seqPhase = PHASE_MOVING;
}

void updateHeardCommandSequence() {
  SequenceStep &step = i2cSequence[sequenceIndex];
  Axis &axis = *step.axis;

  if (seqPhase == PHASE_MOVING) {
    if (driveAxisTrajectory(axis)) {
      seqPhase = PHASE_HOLDING;
      seqHoldStart = millis();
    }
  } else { // PHASE_HOLDING
    if (millis() - seqHoldStart >= SEQUENCE_STEP_HOLD_MS) {
      sequenceIndex++;
      if (sequenceIndex >= I2C_SEQUENCE_LENGTH) {
        enterMode(MODE_IDLE); // sequence finished -> resume idle automatically
      } else {
        startSequenceStep(sequenceIndex);
      }
    }
  }
}

// ---------------------------------------------------------------
// MODES 3 & 4: WALKING / TURNING - continuous cyclic motion.
// Shared logic: settle the "other" axis to 0, then ping-pong the primary
// axis between boundA and boundB until the mode is changed externally.
// ---------------------------------------------------------------
void enterCyclicMode(CyclicModeConfig &cfg) {
  cyclePhase = PHASE_SETTLING;
  startAxisMove(*cfg.otherAxis, 0, MODE_SETTLE_DURATION);
}

void updateCyclicMode(CyclicModeConfig &cfg) {
  if (cyclePhase == PHASE_SETTLING) {
    if (driveAxisTrajectory(*cfg.otherAxis)) {
      // pick whichever bound is closer to start the cycle smoothly
      float distA = fabs(cfg.primaryAxis->commandedAngle - cfg.boundA);
      float distB = fabs(cfg.primaryAxis->commandedAngle - cfg.boundB);
      cycleAtBoundB = (distB < distA);
      startAxisMove(*cfg.primaryAxis, cycleAtBoundB ? cfg.boundB : cfg.boundA, cfg.stepDuration);
      cyclePhase = PHASE_MOVING;
    }
  } else if (cyclePhase == PHASE_MOVING) {
    if (driveAxisTrajectory(*cfg.primaryAxis)) {
      if (cfg.holdMs > 0) {
        cyclePhase = PHASE_HOLDING;
        cycleHoldStart = millis();
      } else {
        cycleAtBoundB = !cycleAtBoundB;
        startAxisMove(*cfg.primaryAxis, cycleAtBoundB ? cfg.boundB : cfg.boundA, cfg.stepDuration);
      }
    }
  } else { // PHASE_HOLDING
    if (millis() - cycleHoldStart >= cfg.holdMs) {
      cycleAtBoundB = !cycleAtBoundB;
      startAxisMove(*cfg.primaryAxis, cycleAtBoundB ? cfg.boundB : cfg.boundA, cfg.stepDuration);
      cyclePhase = PHASE_MOVING;
    }
  }
}

// ---------------------------------------------------------------
// Mode switching
// ---------------------------------------------------------------
void enterMode(Mode m) {
  currentMode = m;
  switch (m) {
    case MODE_IDLE:
      resumeStandby(yawAxis);
      resumeStandby(pitchAxis);
      break;
    case MODE_HEARD_COMMAND:
      sequenceIndex = 0;
      startSequenceStep(0);
      break;
    case MODE_WALKING:
      enterCyclicMode(walkConfig);
      break;
    case MODE_TURNING:
      enterCyclicMode(turnConfig);
      break;
  }
}

// Called by the Wire library when data arrives at I2C_ADDRESS.
// Keep this minimal - it runs in an interrupt context.
void onI2CReceive(int numBytes) {
  if (numBytes > 0) {
    i2cCommandValue = Wire.read();
    while (Wire.available()) Wire.read(); // drain any extra bytes
  }
  i2cCommandPending = true;
}

void setup() {
  yawServo.attach(YAW_PIN, SERVO_PULSE_MIN, SERVO_PULSE_MAX);
  pitchServo.attach(PITCH_PIN, SERVO_PULSE_MIN, SERVO_PULSE_MAX);

  randomSeed(analogRead(A0)); // leave A0 floating/unconnected for good randomness

  initAxis(yawAxis, &yawServo, YAW_MIN_ANGLE, YAW_MAX_ANGLE);
  initAxis(pitchAxis, &pitchServo, PITCH_MIN_ANGLE, PITCH_MAX_ANGLE);

  // Mode 2 sequence: zero the yaw, then nod pitch (+45 -> -10) twice, then settle to 0.
  i2cSequence[0] = { &yawAxis,   0,   1000 };
  i2cSequence[1] = { &pitchAxis, 45,  900  };
  i2cSequence[2] = { &pitchAxis, -10, 900  };
  i2cSequence[3] = { &pitchAxis, 45,  900  };
  i2cSequence[4] = { &pitchAxis, -10, 900  };
  i2cSequence[5] = { &pitchAxis, 0,   900  };

  Wire.begin(I2C_ADDRESS);
  Wire.onReceive(onI2CReceive);

  // currentMode starts as MODE_IDLE by default - initAxis() above already put
  // both axes into a live idle "looking around" move, so no extra call needed.
}

void loop() {
  // Check for a new mode command from the speech-to-text host.
  if (i2cCommandPending) {
    i2cCommandPending = false;
    Mode newMode = currentMode;
    bool valid = true;
    switch (i2cCommandValue) {
      case CMD_IDLE:          newMode = MODE_IDLE;          break;
      case CMD_HEARD_COMMAND: newMode = MODE_HEARD_COMMAND; break;
      case CMD_WALKING:       newMode = MODE_WALKING;       break;
      case CMD_TURNING:       newMode = MODE_TURNING;       break;
      default: valid = false; break; // unrecognized byte, ignore
    }
    if (valid && newMode != currentMode) {
      enterMode(newMode);
    }
  }

  switch (currentMode) {
    case MODE_IDLE:
      updateStandbyAxis(yawAxis);
      updateStandbyAxis(pitchAxis);
      break;
    case MODE_HEARD_COMMAND:
      updateHeardCommandSequence();
      break;
    case MODE_WALKING:
      updateCyclicMode(walkConfig);
      break;
    case MODE_TURNING:
      updateCyclicMode(turnConfig);
      break;
  }

  delay(10); // ~100Hz refresh
}

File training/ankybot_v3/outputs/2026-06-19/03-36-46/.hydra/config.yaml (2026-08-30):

env:
  viewer:
    eye:
    - 7.5
    - 7.5
    - 7.5
    lookat:
    - 0.0
    - 0.0
    - 0.0
    cam_prim_path: /OmniverseKit_Persp
    resolution:
    - 1280
    - 720
    origin_type: world
    env_index: 0
    asset_name: null
    body_name: null
  sim:
    device: cuda:0
    dt: 0.002
    gravity:
    - 0.0
    - 0.0
    - -9.81
    physics_prim_path: /physicsScene
    physics_material:
      func: isaaclab.sim.spawners.materials.physics_materials:spawn_rigid_body_material
      static_friction: 0.5
      dynamic_friction: 0.5
      restitution: 0.0
      friction_combine_mode: average
      restitution_combine_mode: average
      compliant_contact_stiffness: 0.0
      compliant_contact_damping: 0.0
    use_fabric: true
    render_interval: 5
    enable_scene_query_support: false
    physics: null
    render:
      enable_translucency: null
      enable_reflections: null
      enable_global_illumination: null
      antialiasing_mode: null
      enable_dlssg: null
      enable_dl_denoiser: null
      dlss_mode: null
      enable_direct_lighting: null
      samples_per_pixel: null
      enable_shadows: null
      enable_ambient_occlusion: null
      dome_light_upper_lower_strategy: null
      carb_settings: null
      rendering_mode: null
    create_stage_in_memory: false
    logging_level: WARNING
    save_logs_to_file: true
    log_dir: null
    visualizer_cfgs: []
  ui_window_class_type: isaaclab.envs.ui.manager_based_rl_env_window:ManagerBasedRLEnvWindow
  seed: null
  decimation: 10
  scene:
    num_envs: 1024
    env_spacing: 1.0
    lazy_sensor_update: true
    replicate_physics: true
    filter_collisions: true
    clone_in_fabric: false
    robot:
      class_type: isaaclab.assets.articulation.articulation:Articulation
      prim_path: '{ENV_REGEX_NS}/Robot'
      spawn:
        func: isaaclab.sim.spawners.from_files.from_files:spawn_from_usd
        visible: true
        semantic_tags: null
        copy_from_source: true
        spawn_path: null
        mass_props: null
        deformable_props: null
        rigid_props:
          rigid_body_enabled: null
          kinematic_enabled: null
          disable_gravity: false
          linear_damping: 0.0
          angular_damping: 0.0
          max_linear_velocity: 100.0
          max_angular_velocity: 100.0
          max_depenetration_velocity: 1.0
          max_contact_impulse: null
          enable_gyroscopic_forces: null
          retain_accelerations: false
          solver_position_iteration_count: null
          solver_velocity_iteration_count: null
          sleep_threshold: null
          stabilization_threshold: null
        collision_props: null
        activate_contact_sensors: true
        scale: null
        articulation_props:
          articulation_enabled: null
          enabled_self_collisions: false
          solver_position_iteration_count: 8
          solver_velocity_iteration_count: 2
          sleep_threshold: null
          stabilization_threshold: null
          fix_root_link: null
        fixed_tendons_props: null
        spatial_tendons_props: null
        joint_drive_props: null
        visual_material_path: material
        visual_material: null
        usd_path: /workspace/custom_assets/Ankybot_v3_description/usd_v3/World0.usd
        variants: null
      init_state:
        pos:
        - 0.0
        - 0.0
        - 0.25
        rot:
        - 0.0
        - 0.0
        - 0.0
        - 1.0
        lin_vel:
        - 0.0
        - 0.0
        - 0.0
        ang_vel:
        - 0.0
        - 0.0
        - 0.0
        joint_pos:
          .*_Hip_Joint: 0.0
          .*_Thigh_Joint: 0.5236
          .*_Foot_Joint: 0.384
        joint_vel:
          .*: 0.0
      collision_group: 0
      debug_vis: false
      articulation_root_prim_path: null
      soft_joint_pos_limit_factor: 0.95
      actuators:
        legs:
          class_type: isaaclab.actuators.actuator_pd:IdealPDActuator
          joint_names_expr:
          - .*_Hip_Joint
          - .*_Thigh_Joint
          - .*_Foot_Joint
          effort_limit: 3.92266
          velocity_limit: 10.4719755
          effort_limit_sim: 3.92266
          velocity_limit_sim: 10.4719755
          stiffness:
            .*_Hip_Joint: 20.0
            .*_Thigh_Joint: 20.0
            .*_Foot_Joint: 18.0
          damping:
            .*_Hip_Joint: 0.8
            .*_Thigh_Joint: 0.8
            .*_Foot_Joint: 0.8
          armature: null
          friction: null
          dynamic_friction: null
          viscous_friction: null
      actuator_value_resolution_debug_print: false
    ground:
      class_type: null
      prim_path: /World/ground
      spawn:
        func: isaaclab.sim.spawners.from_files.from_files:spawn_ground_plane
        visible: true
        semantic_tags: null
        copy_from_source: true
        spawn_path: null
        usd_path: https://omniverse-content-staging.s3-us-west-2.amazonaws.com/Assets/Isaac/6.0/Isaac/Environments/Grid/default_environment.usd
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

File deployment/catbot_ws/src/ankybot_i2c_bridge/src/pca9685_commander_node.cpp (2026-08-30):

#include <rclcpp/rclcpp.hpp>
#include <sensor_msgs/msg/joint_state.hpp>

#include <algorithm>
#include <array>
#include <chrono>
#include <cmath>
#include <memory>
#include <stdexcept>
#include <string>
#include <unordered_map>
#include <vector>

#include "ankybot_i2c_bridge/pca9685.hpp"

namespace
{
constexpr int NUM_SERVOS = 12;
constexpr float PI_F = 3.14159265f;
constexpr float HALF_PI_F = 1.57079632679f;

const std::array<std::string, NUM_SERVOS> JOINT_ORDER = {
  "FL_Hip_Joint", "FL_Thigh_Joint", "FL_Foot_Joint",
  "FR_Hip_Joint", "FR_Thigh_Joint", "FR_Foot_Joint",
  "BL_Hip_Joint", "BL_Thigh_Joint", "BL_Foot_Joint",
  "BR_Hip_Joint", "BR_Thigh_Joint", "BR_Foot_Joint",
};

int JOINT_ORIENTATION[NUM_SERVOS] = {
  -1, 1, -1, //FL
  -1, -1, 1, //FR
  1, -1, 1, //BL
  1, 1, -1  //BR
};

constexpr float DEG_TO_RAD_F = 0.01745329252f;

// per-channel physical zero-position trim (degrees), corrects for gear-tooth assembly slop, applied in raw servo-angle space, after JOINT_ORIENTATION.
// Hardware-measured via `ros2 topic pub /joint_commands` (data[i] found by hand that reaches true physical zero with trim=0, back-solved as T_deg[i] = JOINT_ORIENTATION[i] * data[i] * (180/pi)).
float JOINT_ZERO_TRIM_DEG[NUM_SERVOS] = {
  0.0f, 2.8648f, 2.8648f,  //FL
  8.5944f, 8.5944f, 5.7296f,  //FR
  2.8648f, 5.7296f, 8.5944f,  //BL
  5.7296f, 2.8648f, 8.5944f   //BR
};

float JOINT_RANGE_MIN_DEG[NUM_SERVOS] = {
  -70.0f, -40.0f, -30.0f,  //FL
  -70.0f, -40.0f, -30.0f,  //FR
  -65.0f, -40.0f, -30.0f,  //BL
  -60.0f, -40.0f, -30.0f   //BR
};
float JOINT_RANGE_MAX_DEG[NUM_SERVOS] = {
  70.0f, 90.0f, 90.0f,  //FL
  70.0f, 90.0f, 90.0f,  //FR
  65.0f, 90.0f, 90.0f,  //BL
  60.0f, 90.0f, 90.0f   //BR
};

double clampToJointRange(int i, double logical_angle_rad)
{
  double lo = static_cast<double>(JOINT_RANGE_MIN_DEG[i]) * DEG_TO_RAD_F;
  double hi = static_cast<double>(JOINT_RANGE_MAX_DEG[i]) * DEG_TO_RAD_F;
  return std::max(lo, std::min(hi, logical_angle_rad));
}

int angleToPulse(float angle_rad, int servo_min, int servo_max)
{
  float shifted = angle_rad + HALF_PI_F;  // remap to [0, PI]
  shifted = std::max(0.0f, std::min(PI_F, shifted));
  return servo_min +
    static_cast<int>((shifted / PI_F) * static_cast<float>(servo_max - servo_min) + 0.5f);
}
}  // namespace

class PCA9685CommanderNode : public rclcpp::Node
{
public:
  PCA9685CommanderNode()
  : Node("pca9685_commander")
  {
    declare_parameter("i2c_bus", 1);
    declare_parameter("pca9685_address", 0x60);
    declare_parameter("pwm_freq_hz", 300.0);
    declare_parameter("servo_min", 614);
    declare_parameter("servo_max", 3072);
    // identity-maps index i -> channel i by default; known wiring defect (not fixable here): BR_Foot (11) inert, FL_Foot (2) drives two legs.
    declare_parameter(
      "servo_channels", std::vector<int64_t>{0, 1, 2, 3, 4, 5, 6, 7, 8, 9, 10, 11});
    declare_parameter("servo_neutral", std::vector<double>(NUM_SERVOS, 0.0));
    declare_parameter("joint_commands_topic", std::string("/joint_commands"));
    // deadband: drop a re-command within this many radians of the last driven value, to avoid servo dither from upstream jitter.
    declare_parameter("deadband_rad", 0.01);
    deadband_rad_ = get_parameter("deadband_rad").as_double();

    for (int i = 0; i < NUM_SERVOS; ++i) {
      joint_index_[JOINT_ORDER[i]] = i;
    }

    servo_min_ = static_cast<int>(get_parameter("servo_min").as_int());
    servo_max_ = static_cast<int>(get_parameter("servo_max").as_int());

    auto channels_param = get_parameter("servo_channels").as_integer_array();
    servo_channels_.assign(channels_param.begin(), channels_param.end());

    auto neutral_param = get_parameter("servo_neutral").as_double_array();
    servo_neutral_.assign(neutral_param.begin(), neutral_param.end());

    if (static_cast<int>(servo_channels_.size()) != NUM_SERVOS ||
      static_cast<int>(servo_neutral_.size()) != NUM_SERVOS)
    {
      // config error, not connectivity, still fatal (caught in main()), unlike the I2C failures handled below.
      throw std::runtime_error("servo_channels/servo_neutral must have exactly 12 entries");
    }

    bus_number_ = static_cast<int>(get_parameter("i2c_bus").as_int());
    address_ = static_cast<int>(get_parameter("pca9685_address").as_int());
    freq_ = get_parameter("pwm_freq_hz").as_double();

    std::string topic = get_parameter("joint_commands_topic").as_string();
    subscription_ = create_subscription<sensor_msgs::msg::JointState>(
      topic, 10,
      std::bind(&PCA9685CommanderNode::callback, this, std::placeholders::_1));

    // first connect attempt (reports immediately if it fails, see tryConnect()); the timer below retries forever after this.
    tryConnect();
    reconnect_timer_ = create_wall_timer(
      std::chrono::seconds(3), std::bind(&PCA9685CommanderNode::tryConnect, this));
  }
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

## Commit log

2026-08-30 Initial commit: Ankybot training (v2/v3) and ROS2 deployment code
    [BLFoot.STL, BLHip.STL, BLThigh.STL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]
2026-08-30 Add custom_assets USD descriptions referenced by training configs
    [BLFoot.STL, BLHip.STL, BLKneeLink.STL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]
2026-08-30 Add ENGINEERING.md write-up, MIT LICENSE, and README links
    Curated summary of the harder debugging threads from the project's
    internal dev log (reward-gaming exploit fix, sim-to-real actuator
    recalibration, joint-velocity ablation study, I2C bus contention fix,
    and the recovery-curriculum training approach).
2026-08-30 Sync ROS 2 packages to current state, add Arduino firmware, calibration tooling, and USD textures
    - deployment/catbot_ws/src, topic_pub_scripts: update to match current
    ros2_copy (I2C bus split, velocity smoothing, bringup systemd service,
    and the earlier API-key scrub), without removing already-archived
    superseded files (no_sensor_policy, check_wifi/microphone, etc.)
    - deployment/hardware/arduino_firmware (new): production Mega I2C slave
    firmware, dino head prop firmware, utility sketches
    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
    [calibration_samples.csv, range10_fwd_rep1.csv, range10_fwd_rep2.csv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]
2026-08-30 Resync deployment/hardware/URDFs/{ankybot_v2,ankybot_v3} to current custom_assets
    These had drifted from the training-authoritative copy in
    training/custom_assets (stale World4.usd/base.usd/physics.usd, a few
    leftover one-off experimental files). Replaced with exact copies so
    both locations agree.
    [BLFoot.STL, BLHip.STL, BLThigh.STL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]
